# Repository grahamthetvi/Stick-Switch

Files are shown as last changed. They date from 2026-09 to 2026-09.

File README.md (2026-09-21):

# Stick-Switch

Single-axis **forward** pencil-grip stick for two-level AAC / iPad Switch Control. Soft→hard is an **upgrade** (HID `1` then `2`), never a double-select. The APH Adaptable Stick Switch (`1-08615-00`) stays the binary classroom backup on the **full** kit.

Student motion: thumb + index **push forward**. Not a 360° wobble.

## Kits

Same printed chassis for all three. Sensor methods 2 / 3 / 4a / 4b are modules that drop into that chassis; they are not separate prints.

| Kit | Cost | Power | What you get |
| --- | --- | --- | --- |
| **Wired** | Affordable | None | Method 3 D2F clicks + 3.5 mm TS cord. Binary PowerLink / switch-box. |
| **USB bank** | Affordable | USB power bank → ESP32 | Two-level BLE HID, analog modules, FET jack. No AA / boost. `PACK USB`. |
| **Full** | Full | 2× or 3× AA + boost | Same as USB bank, self-contained. APH on GPIO33. Classroom default if you want in-chassis power. |

Start **wired** to trial the click feel. Add the ESP32 on USB for two-level HID. Move to **full** when you want the pack inside the box.

Later sensor swaps (same chassis): Method 4b if travel is too small (chassis-mounted TAL220 saddle — it does **not** fit the 40×32 mm pocket). Method 2 if clicks are disliked. Method 4a for software trip points.

## What to print

Shared print list (part, material, and bed orientation). All three kits:

| Part | Material | Notes |
| --- | --- | --- |
| `base_chassis` | PETG | Floor on the bed |
| `cover_slot` | PETG | Interior face on the bed |
| `rocker_arm` | PETG | Hub face on the bed; bearings are in the towers only |
| `stick_collar` | PETG | |
| `grip_sleeve` `bellows` `tpu_foot` ×4 | TPU 95A | |
| `p_clip` | PETG | Pad on the bed; TPU 95A optional for extra grip. Print a **second** for USB-bank cable. |
| `mod3_switch_plate` | PETG | ID resistor **10k** to GND (skip the resistor on wired-only) |
| `mod3_ramp_cam` | PETG | Optional |
| `aa_2x_shim` | PETG | **Full** kit only, and only if using a 2x AA holder |

Exploded look: `openscad -D 'part="kit_preview"' cad/stick_switch.scad` (not an STL).

PETG 0.20 mm, 5 perimeters, 40% gyroid. STLs: `cad/stl/` (`bash cad/export_all.sh`).

## Wired (affordable)

Method 3 clicks + a **3.5 mm TS cord**. No ESP32, AA pack, or boost. AA well and ESP32 tray stay empty. Either click closes the cord — **binary** PowerLink / switch-box. Two-level HID needs [USB bank](#usb-bank-affordable) or [Full](#build).

Gold D2Fs. NC taped. Flying cord through the jack hole is cheapest; SJ1-3513N is optional.

```
D2F-01F-D3 COM → cord sleeve
D2F-01-D3  COM → cord sleeve
D2F-01F-D3 NO  → cord tip
D2F-01-D3  NO  → cord tip
```

`p_clip` on the +Y inner wall, 40 mm loop. Skip ESP32, AA holder, MT3608, slide, ID resistors, 2N7000, APH, module header. Diodes are only needed when GPIO is also attached — if you will drop in an ESP32 later, populate the Method 3 1N4148 diode-OR to the jack now.

## USB bank (affordable)

Drop the ESP32 into the existing tray. USB-A → Micro-USB through the rear **18 × 12 mm** cut (cover has a matching rear-edge notch). Second `p_clip` on the −X inner floor, +Y of the USB window. User-supplied bank — some banks auto-off at low load; BLE idle usually keeps them awake.

Skip AA, boost, slide, Schottky (USB 5 V on the DevKit already powers analog + the GPIO27 FET jack). Serial `PACK USB` (DUMP `"pack":0`; no low-batt blink). Analog modules use the existing FET jack netlists. Method 3 diode-OR still works with board power off.

Flash and pair as in [Build](#build) steps 8–10, but leave the AA well empty and use `PACK USB` instead of `PACK 3`. No VIN fight (no pack).

## Build

**Full** kit: Method 3 + in-chassis AA + APH `1-08615-00` on GPIO33. Do these in order. Pin map, netlists, and later sensor methods stay in the sections below. Wired and USB-bank kits skip the AA / APH steps.

Web Serial calibrator on GitHub Pages: <https://grahamthetvi.github.io/Stick-Switch/> (this README is the build guide). Enable once: **Settings → Pages → Source: GitHub Actions**.

### 1. Print

Print the [shared list](#what-to-print). **`aa_2x_shim` only for a 2x AA holder** on this full kit.

### 2. Heat-set, hinge, cover

Brass inserts into PETG with a soldering iron. Posts stay hot — burn hazard. Let them cool before handling.

- Cover: 4× short M3 inserts in the corner posts (from the top).
- Module bay: 4× M2.5 inserts in the pocket floor (34×26 mm) — M3 does not fit the 40×32 mm plate.
- Mount: 1/4-20 insert from the underside **under the stick**, not under the AA well.
- Chassis tray and Method 4b: M3 through-slots (3.3 mm). No heat-set. D2F / Hall hardware stays M2.

Hinge: press one **623ZZ** into each tower (not the rocker). **M3×20** through both. McMaster **9271K22** LH 90° torsion spring on the left-tower 4.4 mm boss. One leg in a preload hole (start at 60°); the other on the rocker. **Do not mix 9271K21 RH.** Spring legs can fly off — eye protection, hold both legs until the cover is on.

Cover screws into the M3 inserts. Cover M3 set-screw is the travel stop (12 mm grip / 14 mm slam). 8.0 mm OD × 140 mm 6061 through `stick_collar`, TPU `grip_sleeve` over the tube, TPU `bellows` into the cover groove. Four TPU feet. `p_clip` on the +Y inner wall, −X of the jack: M3 through the clip and floor, nut on the underside, **40 mm** slack loop. 0.4 mm foam on the cover stop. Loctite 222 after a classroom trial, not before.

### 3. Wire Method 3

Gold contacts only — no silver D2F on GPIO. Soft **D2F-01F-D3** → GPIO18. Hard **D2F-01-D3** → GPIO19. COM → GND. NC taped.

```
D2F-01F-D3 COM → GND
D2F-01F-D3 NO  → GPIO18 and 1N4148 anode
D2F-01-D3  COM → GND
D2F-01-D3  NO  → GPIO19 and 1N4148 anode
both 1N4148 cathodes → jack Tip
jack Sleeve → GND
ID 10k between header pin 8 and GND
```

Optional LEDs: GPIO25 soft, GPIO26 hard, GPIO16 grip (GPIO → 330 Ω → LED anode; cathode → GND). Optional piezo GPIO13.

### 4. APH backup

APH Adaptable Stick Switch **1-08615-00** on **GPIO33 + GND** the same day. Solder or a flying 3.5 mm TS pigtail (tip → GPIO33, sleeve → GND). The chassis **SJ1-3513N is PowerLink OUTPUT**, not an APH input — do not plug the APH into it.

### 5. Install AA pack

Well **60 × 50 × 18 mm** on −Y. Prefer 3x AA for the full kit. AA holder options (pack, Keystone part, Digi-Key SKU, and well fit):

| Pack | Holder | Digi-Key | Fit |
| --- | --- | --- | --- |
| 3x AA | Keystone **2465** (6″ leads) or **2464** (PC pins) | `36-2465-ND` / `36-2464-ND` | ~58 × 48 × 17 mm |
| 2x AA | Keystone **2463** (6″ leads) or **2462** (PC pins) | `36-2463-ND` / `36-2462-ND` | ~58 × 32 × 17 mm; print `aa_2x_shim` into +Y slack |

Snap-on 9V-style Keystone **2475** (3x) / **2474** (2x) also fit; add a 9V snap pigtail. Amazon clones are fine if they measure those envelopes. (Older notes said 2468 / 2466-class — those SKUs are AAA / not this well.)

```
holder + → SS-12F15 → MT3608 IN
MT3608 5.0 V → 1N5819/SS14 Schottky → ESP32 VIN
holder − → GND
100k / 100k from pack + → GPIO34 → GND
```

Alkaline AA, polarity as marked on the holder. **No in-chassis charging.** Slide **OFF** while programming (USB 5 V fights VIN if the switch is ON). Serial `PACK 2` or `PACK 3`. No AA: [USB bank](#usb-bank-affordable) and `PACK USB`.

### 6. Connect PowerLink

Same Sky **SJ1-3513N**: tip = NO, sleeve = GND, ring unused. 3.5 mm **TS** cable from this jack into the AbleNet PowerLink **SWITCH** jack. Independent of BLE and of `PROFILE`. Method 3 diode-OR closes the jack with the ESP32 **off**. Analog FET (GPIO27 / 2N7000) needs board power.

### 7. Grip LED (optional)

Isolate the 6061 tube in the PETG `stick_collar`. Run a wire from the tube (collar slot) to GPIO14 (touch T6). LED on GPIO16 only — never HID, never jack. Serial `GRIP CAL` at rest; `GRIP THRESH <n>` if needed.

### 8. Flash

Install [PlatformIO Core](https://docs.platformio.org/en/latest/core/installation/index.html) (or the VS Code PlatformIO IDE). Slide switch OFF.

```
cd firmware/stick_switch
pio run -e esp32dev --target upload
pio device monitor -b 115200
```

If upload fails: hold **BOOT**, tap EN, release BOOT, retry. Type `HELP` then `DUMP`.

### 9. First boot

Slide ON. Serial:

```
PACK 3
PROFILE IPADOS
```

Use `PACK 2` if the holder is 2x AA. Pair BLE keyboard `Stick-Switch-XXXX` (last two MAC bytes). iPad **Settings → Accessibility → Switch Control → Switches → External**: `1` = Move to Next Item, `2` = Select Item. Chrome/Edge calibrator: <https://grahamthetvi.github.io/Stick-Switch/> (`tools/calibrate.html`, Web Serial, 115200). Method 3 clicks need **no** analog CAL.

### 10. Full-kit bench

Same checks as [Bench](#bench-all-methods) below: luggage scale, `PLOT 1`, Notes app `1` then `2`, Method 3 jack continuity with power off.

## HID / iPad

Pair the ESP32 BLE keyboard named `Stick-Switch-XXXX` (last two MAC bytes; manufacturer **Graham Labs**). Then **Settings → Accessibility → Switch Control → Switches → External**:

- `1` = Move to Next Item
- `2` = Select Item

Firmware never holds both keys. Crossing hard **releases the soft key and presses the hard key**. Easing off hard without a full release stays on hard. Full release clears keys. Profiles change which HID codes those levels send; they do **not** change the jack.

HID key map by `PROFILE` (soft, hard, and binary/APH):

| `PROFILE` | Soft | Hard | Binary / APH |
| --- | --- | --- | --- |
| `IPADOS` (default) | `1` | `2` | Space |
| `ANDROID` | Tab | Return | Return |
| `FUNCTION` | F1 | F2 | F3 |
| `MEDIA` | vol down | vol up | play/pause |
| `CUSTOM` | NVS `KEYS` / `BINARY_KEY` | | |

Serial: `PROFILE IPADOS`, `MODE BINARY`, `BINARY_KEY SPACE`. `KEYS` / `BINARY_KEY` switch to `CUSTOM` and persist.

## Firmware

ESP32 DevKit V1 / WROOM, PlatformIO env `esp32dev` (`firmware/stick_switch`). Uses NimBLE + ESP32 BLE Keyboard. **ADC1 only** (GPIO32 sensor, GPIO34 battery, GPIO35 module ID). Do not use ADC2 — BLE owns the radio.

```
cd firmware/stick_switch
pio run -e esp32dev --target upload
pio device monitor -b 115200
```

If upload fails, hold **BOOT**, tap EN, release BOOT. Full-kit procedure: [Build](#build). USB-bank: [USB bank](#usb-bank-affordable). Wired has no firmware.

Native policy tests (no hardware):

```
make -C firmware/native_test test
```

USB serial 115200. `HELP` lists commands. Chrome/Edge calibrator: <https://grahamthetvi.github.io/Stick-Switch/> (same file as `tools/calibrate.html`; Web Serial needs HTTPS or localhost). Wizard is Rest/TARE → hold soft/CAL SOFT → hold hard/CAL HARD. `MODE`, `PROFILE`, `PACK` (`2` / `3` / `USB`), `TARE`, `CAL STOP`, `KEYS`, `BINARY_KEY`, `INVERT`, `LUT`, `SCALE`, `GRIP THRESH`, and `GRIP CAL` **auto-save to NVS**. Classroom power-cycle keeps cal. `SAVE` is still an explicit dump confirmation.

BOOT button (GPIO0, after setup): 1 tap = simulate soft, 2 taps = simulate hard, hold = TARE (or CAL start/stop if already collecting / analog held). Optional piezo on GPIO13: startup, paired, click, low battery (silent if unpopulated).

ESP32 pin map (GPIO and function):

| GPIO | Function |
| --- | --- |
| 0 | BOOT diagnostics (INPUT_PULLUP after setup) |
| 18 | SW_SOFT (INPUT_PULLUP) |
| 19 | SW_HARD (INPUT_PULLUP) |
| 33 | APH backup (INPUT_PULLUP) |
| 32 | ADC FSR / Hall (ADC1_CH4) |
| 34 | Pack millivolts (ADC1_CH6), 100k/100k from pack + |
| 35 | Module ID (ADC1_CH7), header pin 8 |
| 21 / 22 | I2C SDA / SCL (NAU7802) |
| 4 | TARE |
| 23 | CAL (reserved; serial is primary) |
| 25 / 26 | LED soft / hard |
| 16 | LED grip (indicator only — never HID, never jack) |
| 27 | JACK_OUT → 2N7000 gate (PowerLink) |
| 14 | Capacitive grip (T6) on isolated 6061 tube |
| 13 | Optional piezo earcon |

NVS modes: `MICRO` `FSR` `HALL` `LOAD` `BINARY`. On boot a valid module ID sets the matching mode; serial `MODE` still overrides for this session (and auto-saves). Empty header keeps the NVS mode. `DUMP` JSON includes `mode`, `profile`, `ble_name`, `level`, `batt_mv`, `batt_pct`, `pack`, `grip`, `module_id`, `module_ohms`, and cal fields. `pack` is `2` / `3` for AA or `0` for `PACK USB`. Idle low-batt LED blink follows the selected AA pack curve (≤15%); USB pack never reports low. Grip hold lights GPIO16 only.

Module ID table (plate, resistor to GND, and `module_id`; 47k pull-up to 3V3 on the chassis):

| Plate | Resistor | `module_id` |
| --- | --- | --- |
| Method 3 | 10k | `MICRO` |
| Method 2 | 22k | `FSR` |
| Method 4a | 47k | `HALL` |
| Method 4b | 100k | `LOAD` |
| none | open | `EMPTY` |

## AA power well and packs

Chassis is **110 × 108 × 32 mm**. One well on the −Y side, **60 × 50 × 18 mm**, takes a 3x AA holder (Keystone **2465** / **2464**, Digi-Key `36-2465-ND` / `36-2464-ND`, ~58 × 48 × 17 mm). A 2x AA holder (Keystone **2463** / **2462**, `36-2463-ND` / `36-2462-ND`, ~58 × 32 × 17 mm) locates in the same well against −Y; print `aa_2x_shim` into the leftover +Y slack. MT3608 sits +X of the holder. No TP4056 — **do not charge AA cells in the chassis**. The 1/4-20 insert stays under the stick, not under the pack. ESP32 stays in the aisle between the towers.

```
AA holder (2x or 3x series) → SS-12F15 slide → MT3608 IN
MT3608 5.0 V → 1N5819/SS14 Schottky → ESP32 VIN
100k / 100k from pack + → GPIO34 → GND
Program: ESP32 USB with the slide switch OFF
```

Serial `PACK 2` / `PACK 3` / `PACK USB` (NVS). Unset pack auto-picks from millivolts on boot (≥3.3 V → 3cell). Curves: 2x empty ~2.0 V full ~3.2 V; 3x empty ~3.0 V full ~4.8 V. BLE HID battery percent and idle low-batt LED use that curve. USB-bank builds skip the AA well: `PACK USB` reports 100% and does not blink low-batt (GPIO34 is floating with no divider).

If USB is live and the switch is ON, 5 V fights at VIN — leave the slide **OFF** while programming. The Schottky stops USB from backfeeding the boost. USB-only (no pack) has no VIN fight.

## PowerLink jack

Same Sky **SJ1-3513N** 3.5 mm TRS, tip = NO, sleeve = GND, ring unused (APH TS plug mates). This is the **PowerLink / wired switch-box output**. It is independent of BLE connection and of `PROFILE`. Method 3 **diode-OR still closes the jack with the ESP32 off**. Analog modules (FSR / Hall / 4b) drive the jack with a 2N7000 from GPIO27 — that path **dies with the board**.

## Grip LED (tube sensor)

Wire the isolated 6061 tube (PETG `stick_collar`) to GPIO14 (touch T6). `touchRead` below the NVS threshold lights GPIO16 only — never HID, never jack. Serial `GRIP THRESH <n>`, `GRIP CAL` (at rest). Fallback: two foil bands on the TPU sleeve, 3.3 V through 1 MΩ, ADC; do not run meaningful current through the student.

## Shared chassis

OpenSCAD: `cad/stick_switch.scad`. STLs: `cad/stl/` (regenerated from this scad; `part="kit_preview"` is exploded shared print only). Export: `bash cad/export_all.sh`. `base_chassis` may warn “not a valid 2-manifold” in OpenSCAD; it is one solid and slices.

Print PETG, 0.20 mm, 5 perimeters, 40% gyroid, no living hinge as the return spring. Shared chassis materials for all three kits (not only the [print list](#what-to-print)):

| Part | Material |
| --- | --- |
| `base_chassis` `cover_slot` `rocker_arm` `stick_collar` `p_clip` | PETG |
| `grip_sleeve` `bellows` `tpu_foot` (×4) `magnet_plug` | TPU 95A |
| Module plates | PETG (TPU puck only on Method 2) |

Tolerances: M3 holes and tray slots 3.3 mm, 623ZZ seats 10.1 mm (`$fn` 72), stick slot 8.4 mm (Y) × 12 mm (X), module pocket 40×32 mm, M2.5 pattern 34×26 mm. D2F / Hall stay M2. Stick: **8.0 mm OD × 140 mm 6061**, grip center **110 mm** from hinge. Cam at **25 mm**. Cover M3 set-screw is the travel stop (12 mm grip / 14 mm slam; **0.4 mm cam** for Method 4b).

Return: McMaster **9271K22** left-hand 90° piano-wire torsion spring (0.281″ OD, 0.172″ shaft, 0.030″ wire, 3.25 coils, 1″ legs, 0.67 in·lbf max at 90°). Do not mix **9271K21** RH. Printed 4.4 mm boss on the left tower; preload holes 0/30/60/90° at 7.5 mm radius. Start at 60° (≈0.5 N at the grip); 90° if the stick feels light. Target **0.5–0.7 N** at grip (luggage scale). Hinge: M3×20 + two **623ZZ in the towers**. Side-load is killed by the cover slot. Mount: 1/4-20 insert, 4× M3 tray slots, Dual Lock SJ3550, TPU feet. Cord: printed `p_clip` + 40 mm loop. USB power-bank: rear-wall **18 × 12 mm** cut + cover notch; second `p_clip` on the −X inner floor. Pinch: TPU bellows, edges R≥2 mm.

8-pin module header (rear, pin 1 = 3V3): `3V3, GND, SOFT, HARD, ADC, SDA, SCL, ID`. ID → GPIO35.

PowerLink jack: Same Sky **SJ1-3513N**. Tip = NO, Sleeve = GND, Ring unused (APH TS plug mates).

## Method 3 — staged microswitches (first trial)

- Soft: Omron **D2F-01F-D3** (0.74 N, gold, solder lug)
- Hard: Omron **D2F-01-D3** (1.47 N, gold)
- `mod3_switch_plate` + optional `mod3_ramp_cam`
- Hard switch **1.6 mm** further from the cam. Target grip travel **4–6 mm / 10–12 mm / 14 mm stop**. 0.4 mm foam on the stop.

Wiring (COM→GND, NO→GPIO, NC taped):

```
D2F-01F-D3 COM → GND
D2F-01F-D3 NO  → GPIO18 and 1N4148 anode
D2F-01-D3  COM → GND
D2F-01-D3  NO  → GPIO19 and 1N4148 anode
both 1N4148 cathodes → jack Tip
jack Sleeve → GND
ID 10k between header pin 8 and GND
```

Firmware: `MODE MICRO`. 1 kHz poll, 15 ms debounce. HARD if GPIO19 low (even if GPIO18 failed). No downgrade until both high 15 ms. Jack still works with ESP32 **off** (diode-OR). No-ESP32 parallel-to-cord wiring: [Wired](#wired-affordable).

Do not use silver D2F parts on GPIO.

## Method 2 — FSR

Adafruit **#166** (Alpha MF01A-N-221-A01) or Interlink **34-00012**. `mod2_anvil` + TPU `mod2_puck` Ø8×3 + `mod2_retainer` (1.4 mm, printable). Do not solder the FSR tail.

```
FSR A → 3V3
FSR B → GPIO32 and 47k to GND
100 nF GPIO32 → GND
GPIO27 → 10k to GND and 2N7000 gate
2N7000 drain → jack Tip; source → GND
ID 22k between header pin 8 and GND
```

`MODE FSR`. 200 Hz, boxcar/8, 8% hysteresis. Until cal: soft = tare+250, hard = tare+1200. Then `TARE`, five hard holds, `CAL START HARD` / `CAL STOP` (stores 35% / 70% of span). Jack FET is dead when the ESP32 is off.

## Method 4a — Hall travel

Honeywell **SS49E** + encapsulated **6×3 mm N35** (not N52). Rest gap 5 mm, stop gap 2 mm. Brass/nylon M2. `mod4a_hall_tray` + `gap_gauge_2`…`6` + `magnet_plug`.

Honeywell TO-92 (verify bag): pin1 Vcc, pin2 GND, pin3 OUT.

```
Vcc → 3V3   GND → GND   OUT → GPIO32
100 nF Vcc–GND   10 nF OUT–GND
jack FET as Method 2
ID 47k between header pin 8 and GND
```

South toward branded face must **raise** ADC; else `INVERT AN 1` or flip magnet. `MODE HALL`. 5-point LUT:

```
LUT 1800,0,2000,3,2300,6,2700,9,3100,12
```

Sweep grip 0–12 mm; span must be ≥800 counts. Soft 5 mm / hard 11 mm / hyst 0.8 mm. Tares at BLE connect via rest ADC (`TARE`). If the student mouths objects, skip this module.

## Method 4b — load cell (later; near-zero travel)

SparkFun **SEN-13329 TAL220 10 kg** (or YZC-133 5 kg) is **55 × 12.7 mm** and does not fit the 40×32 mm module pocket. `mod4b_cell_saddle` is a **72 × 24 mm** chassis-mounted beam that bolts to the M3 slots under the cam — not a 40 mm plate. The TAL220 bar's own holes stay the vendor size (usually M5). Later experiment, not first-print. Adafruit **4538** NAU7802, gain 128, LDO 3.0 V, 80 SPS. `mod4b_ball_anvil`, `feeler_0_4` (0.4 mm **gauge**, not a structural part). Set cover stop to **0.4 mm** cam motion.

```
Red → E+   Black → E−   Green → A+   White → A−
NAU VIN→3V3  GND→GND  SDA→GPIO21  SCL→GPIO22
(no extra I2C pull-ups on STEMMA)
ID 100k between header pin 8 and GND
```

`MODE LOAD`. Soft 120 gf / hard 300 gf / hyst 25 gf until student cal. Quiet slow-tare 1%/3 s only when abs(g) < 15. I2C fail → APH GPIO33 still works. Clone color-code: `INVERT LD 1`. Scale with 500 g on the **grip**: `SCALE <gf_per_count>`. Jack FET is dead when the ESP32 is off.

## Bench (all methods)

1. Luggage-scale **10 presses** at the grip; rewrite thresholds from that, not from 1.2 / 3.0 N defaults.
2. Serial `PLOT 1`: 20 slow, 20 fast, 10 slams. Dual-fire count must be 0.
3. iPad Notes: one stroke types `1` then `2`, never overlapping `12`.
4. Switch Control mapping as above.

Method 3 extra: continuity on each NO; jack closes on either click with power off.

## Student trial (10 min, eyes-free after demo)

Watch: two distinct levels, accidental hard, fatigue, resting on the stick (false soft), inability to unload (spring too strong). Abort the last. Method 4b: “push harder, don’t push farther.”

## Safety

Bellows over the hinge. Encapsulated magnet only. No loose neodymium. Clip the cord with printed `p_clip` (40 mm loop). Overload posts on 4b. Loctite 222 after classroom trial. Alkaline AA only; polarity as marked; no in-chassis charging. Slide switch off in a bag. Heat-set posts burn. Hold **9271K22** legs until the cover is on (do not mix **9271K21** RH).

## BOM

Machine-readable list: [`hardware/bom.csv`](hardware/bom.csv). `used_on` includes `wired` and `usb_bank` (the two affordable kits) plus `full` for in-chassis AA power. Shared mechanics are tagged `wired` because every kit prints them.

## GitHub Pages

<https://grahamthetvi.github.io/Stick-Switch/> is the Web Serial calibrator (canonical HTML: `tools/calibrate.html`). This README is the build guide. Workflow `.github/workflows/pages.yml` copies that file to the Pages artifact as `index.html` (static deploy, not Jekyll). Enable once: repo **Settings → Pages → Build and deployment → Source: GitHub Actions**. Use Chrome or Edge; USB serial **115200**. GitHub Pages is HTTPS (required for Web Serial). Safari and Firefox cannot use Web Serial. The same page includes a USB **data**-cable check (plug a known-working USB device through the cable under test); it does not test 3.5 mm PowerLink / TS cords.

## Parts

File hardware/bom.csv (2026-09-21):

qty | mfr_pn | source | used_on | role
1 | ESP32 DevKit V1 WROOM | Adafruit/Amazon | full,usb_bank | BLE HID MCU; full kit and USB-bank (skip AA on usb_bank)
1 | USB-A to Micro-USB cable | Amazon | usb_bank | Power bank to DevKit V1 USB; user supplies the bank (some banks auto-off at low load)
1 | Keystone 2465 (Digi-Key 36-2465-ND) or 2464 (36-2464-ND) | Digi-Key | full | 3x AA holder ~58x48x17 mm in the 60x50x18 mm well; 2465=6in leads 2464=PC pins; snap-on 2475 also fits
1 | Keystone 2463 (Digi-Key 36-2463-ND) or 2462 (36-2462-ND) | Digi-Key | full | 2x AA holder ~58x32x17 mm; print aa_2x_shim on the +Y side (omit if using 3x); snap-on 2474 also fits
1 | MT3608 boost module (set 5.0 V) | Amazon | full | Pack to 5 V for ESP32 VIN
1 | SS-12F15 or similar SPDT slide | Digi-Key/Amazon | full | Pack switch between holder + and boost VIN
2 | 100k 1% TH | Digi-Key | full | GPIO34 battery divider from pack + (before boost)
1 | 1N5819 or SS14 Schottky | Digi-Key | full | Boost 5 V to ESP32 VIN (blocks USB backfeed into boost)
1 | passive piezo 12 mm (optional) | Digi-Key | chassis | Earcons on GPIO13; omit for silent
3 | 3mm LED + 330R | Digi-Key | chassis | GPIO25 soft / GPIO26 hard / GPIO16 grip (GPIO to R to LED anode; cathode to GND); omit if unused
1 | 3.5 mm TS (2-conductor) patch cable 1-2 m | Amazon/AbleNet | powerlink,wired | Chassis SJ1-3513N or flying cord to AbleNet PowerLink SWITCH jack
2 | printed p_clip (cad/stl/p_clip.stl) | print | chassis,wired,usb_bank | PETG P-clip; one on +Y inner wall −X of jack (40 mm loop); second on −X inner floor for USB-bank cable
2 | M3x8 or M3x10 + nut | Amazon | chassis,wired,usb_bank | p_clip to chassis floor (nut underside); second fastener for USB p_clip
1 | 0.4 mm foam pad | Amazon | method3,wired | Cover travel-stop pad
1 | 24 AWG stranded hookup wire | Digi-Key | chassis,wired | GPIO power jack APH pigtail; wired kit D2F to cord
1 | Loctite 222 purple threadlocker | McMaster/Henkel | chassis,wired | After classroom trial (not before)
1 | wire to 6061 stick (PETG collar isolate) | Digi-Key | chassis | ESP32 touch T6 GPIO14; grip LED GPIO16 only
1 | 47k 1% TH | Digi-Key | chassis | Module ID pull-up GPIO35 to 3V3
1 | 10k 1% TH | Digi-Key | method3 | Module ID resistor to GND (MICRO)
1 | 22k 1% TH | Digi-Key | method2 | Module ID resistor to GND (FSR)
1 | 47k 1% TH | Digi-Key | method4a | Module ID resistor to GND (HALL)
1 | 100k 1% TH | Digi-Key | method4b | Module ID resistor to GND (LOAD)
2 | 623ZZ | Amazon/AliExpress | chassis,wired | Hinge bearings 3x10x4 mm (towers only)
1 | M3x20 steel shoulder or socket cap | McMaster/Amazon | chassis,wired | Hinge pin
1 | 9271K22 | McMaster | chassis,wired | LH 90° piano-wire torsion spring (0.281" OD 0.172" shaft 0.030" wire 3.25 coils 1" legs); do not mix 9271K21 RH
1 | 8.0 mm OD x 1.0 mm wall 6061 tube 140 mm | McMaster | chassis,wired | Pencil-grip stick (touch electrode; PETG collar isolates the grip sleeve)
1 | Same Sky SJ1-3513N | Digi-Key | chassis,wired | PowerLink 3.5 mm TRS jack (tip=NO sleeve=GND); omit on wired-only if using a flying TS cord
1 | 1/4-20 brass heat-set insert | Amazon | chassis,wired | RAM/Manfrotto mount (not under the pack)
4 | M3x10 + nuts (optional) | Amazon | chassis,wired | Tray through-slots; Dual Lock / 1/4-20 work without them
8 | M3 heat-set inserts short | Amazon | chassis,wired | Cover + stick pinch
4 | M2.5x8 + inserts | Amazon | module bay,wired | Module screws 34x26 mm
1 | 2N7000 N-FET | Digi-Key | analog modules,usb_bank | Jack drive GPIO27
1 | 10k 1% TH | Digi-Key | analog modules,usb_bank | 2N7000 gate pulldown
1 | 8-pin 2.54 header pair | Digi-Key | module,usb_bank | 3V3 GND SOFT HARD ADC SDA SCL ID
1 | Omron D2F-01F-D3 | Digi-Key/Mouser | method3,wired | Soft click 0.74 N gold microload
1 | Omron D2F-01-D3 | Digi-Key/Mouser | method3,wired | Hard click 1.47 N gold microload
2 | extra D2F-01F-D3 / D2F-01-D3 | Digi-Key | method3,wired | Spares
4 | M2x8 pan + hex nuts | Amazon | method3,wired | Switch slots
2 | 1N4148 (or BAT54) | Digi-Key | method3,wired | Jack diode-OR; omit on wired-only unless adding ESP32 later
1 | Adafruit 166 Alpha MF01A-N-221-A01 | Adafruit | method2 | 14.7 mm FSR 0.3-10 N
2 | spare FSR 166 or Interlink 34-00012 | Adafruit/Digi-Key | method2 | Tail-tear spares
1 | 47k 1% resistor | Digi-Key | method2 | FSR pulldown
1 | 100 nF ceramic | Digi-Key | analog modules | ADC RC (method 2 FSR / 4a Hall GPIO32)
1 | Honeywell SS49E | Digi-Key/Mouser | method4a | Linear Hall TO-92
2 | 6x3 mm N35 disc magnet | K&J/Amazon | method4a | One installed one spare
1 | 100 nF Vcc | Digi-Key | method4a | Hall decoupling
1 | 10 nF | Digi-Key | method4a | Hall output filter
2 | M2x8 nylon/brass | Amazon | method4a | Non-ferrous gap slot
1 | SparkFun SEN-13329 TAL220 10 kg | SparkFun | method4b | Load cell (YZC-133 5 kg substitute); chassis-mounted saddle not 40 mm plate
1 | Adafruit 4538 NAU7802 | Adafruit | method4b | 24-bit I2C ADC
1 | STEMMA QT / Qwiic cable | Adafruit | method4b | I2C
1 | Ø5 mm steel ball | McMaster | method4b | Anvil
2 | M3x10 locknuts | Amazon | method4b | Saddle to chassis M3 slots under cam
1 | APH 1-08615-00 | APH | backup | Existing binary wobble stick
1 | PETG filament | Amazon | print,wired | Structural
1 | TPU 95A filament | Amazon | print,wired | Grip bellows feet puck plug
1 | 3M Dual Lock SJ3550 | 3M | mount,wired | Tray pads

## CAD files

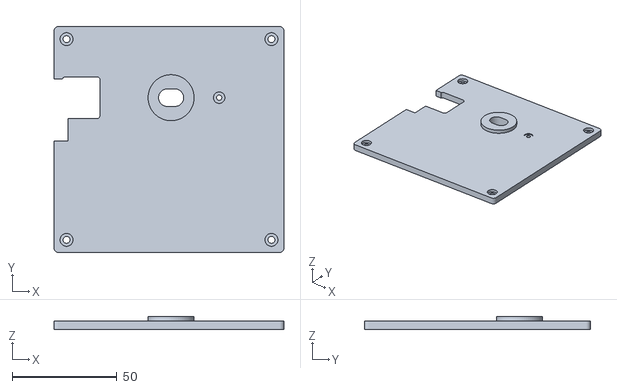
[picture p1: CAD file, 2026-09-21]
cad/stl/cover_slot.stl
110.0 x 108.0 x 6.20

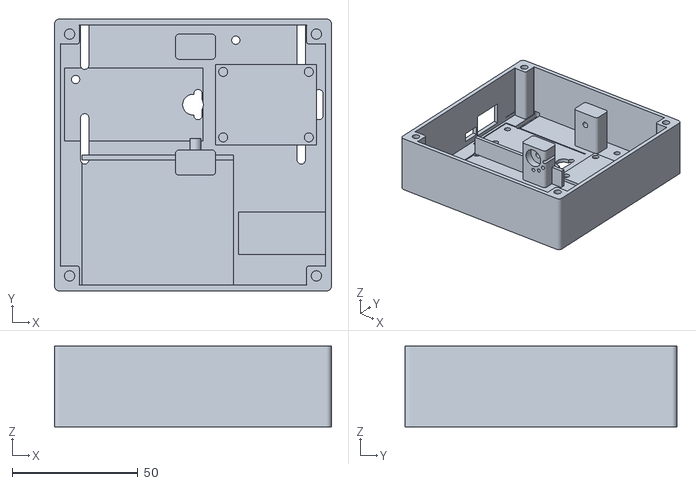
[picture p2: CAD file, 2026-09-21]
cad/stl/base_chassis.stl
110.0 x 108.0 x 32.0

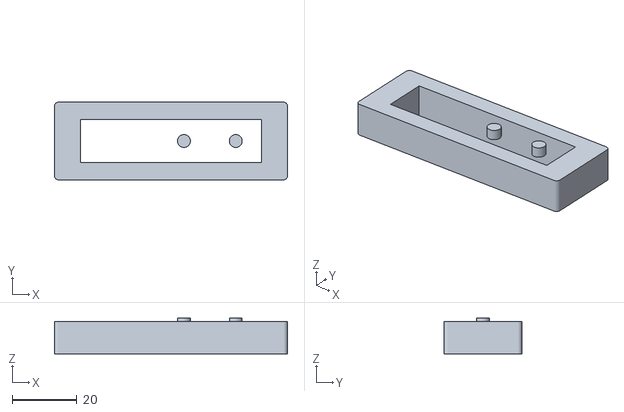
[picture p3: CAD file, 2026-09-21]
cad/stl/mod4b_cell_saddle.stl
72.0 x 24.0 x 11.0

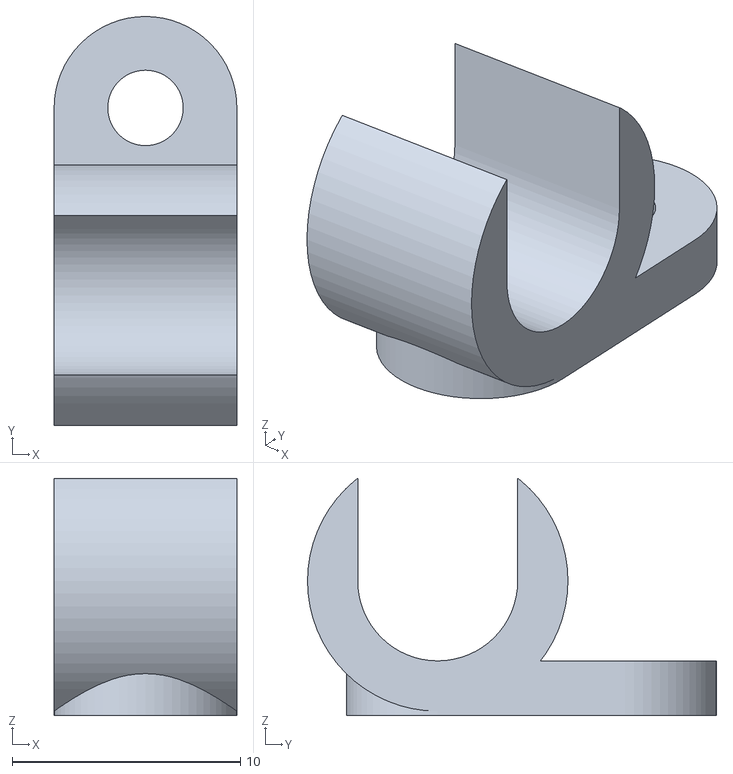
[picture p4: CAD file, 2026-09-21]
cad/stl/p_clip.stl
8.00 x 17.9 x 10.4

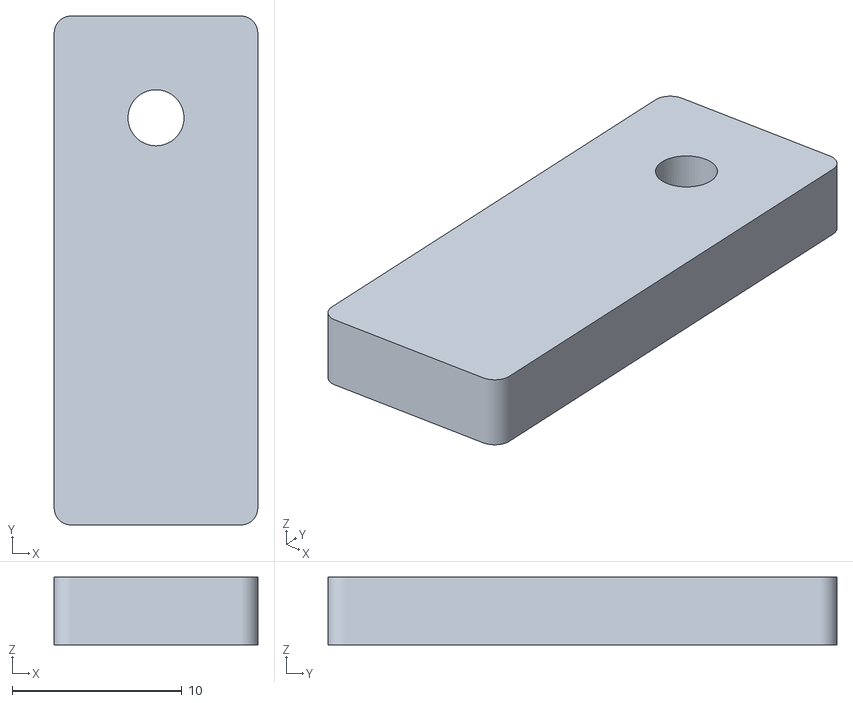
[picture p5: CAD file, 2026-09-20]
cad/stl/gap_gauge_4.stl
12.0 x 30.0 x 4.00

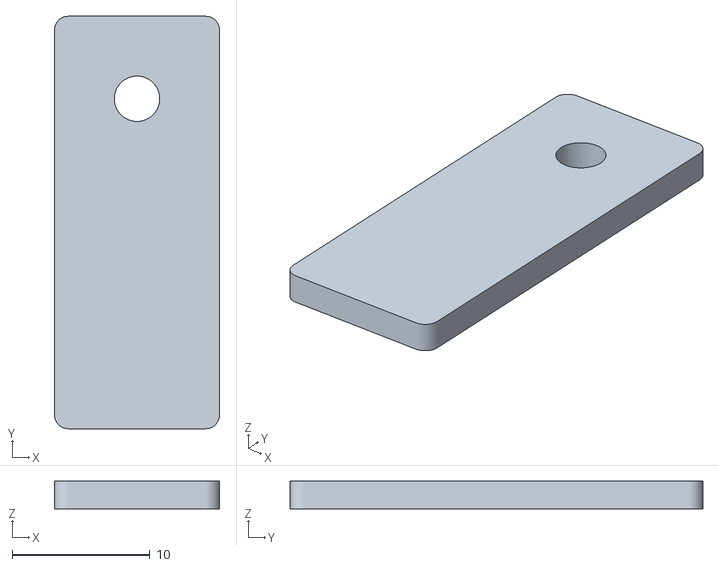
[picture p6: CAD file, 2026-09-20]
cad/stl/gap_gauge_2.stl
12.0 x 30.0 x 2.00

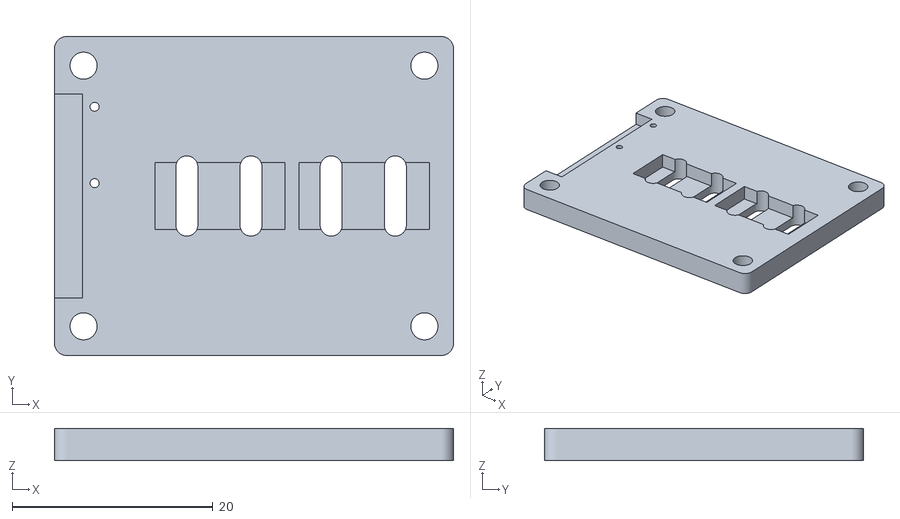
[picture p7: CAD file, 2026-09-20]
cad/stl/mod3_switch_plate.stl
39.8 x 31.8 x 3.20

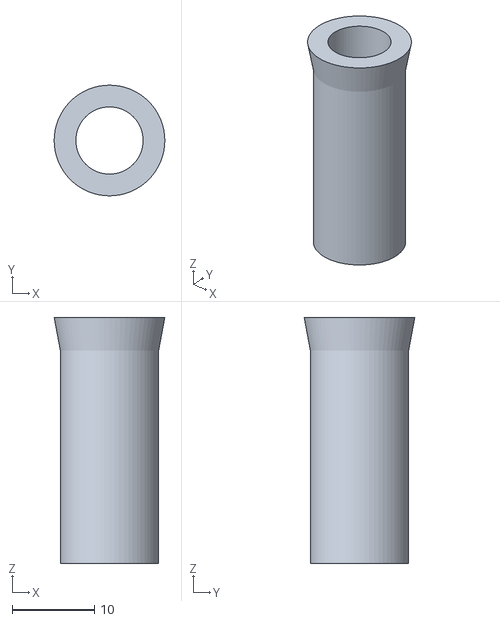
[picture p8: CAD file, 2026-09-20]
cad/stl/grip_sleeve.stl
13.5 x 13.5 x 30.0

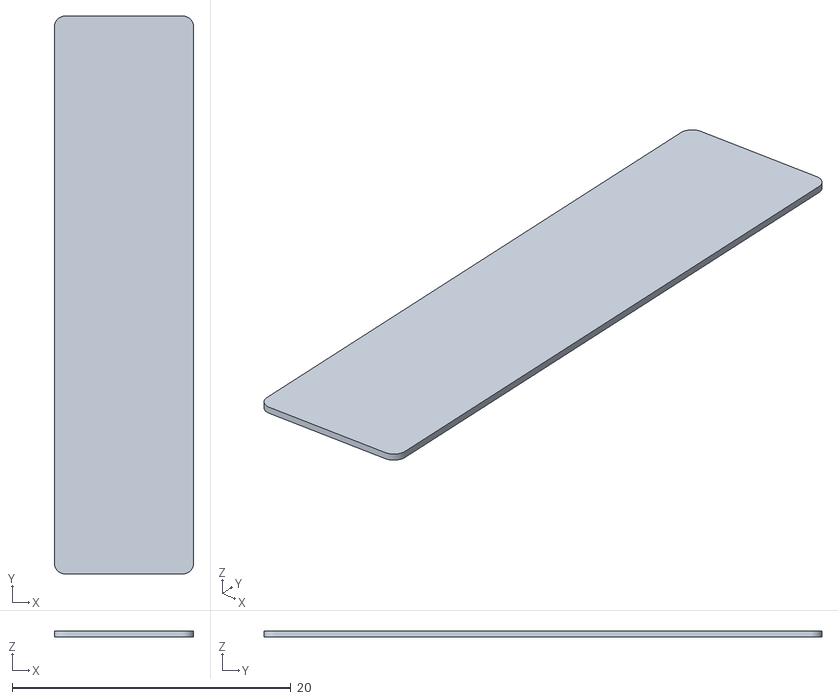
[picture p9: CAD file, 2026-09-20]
cad/stl/feeler_0_4.stl
10.0 x 40.0 x 0.4

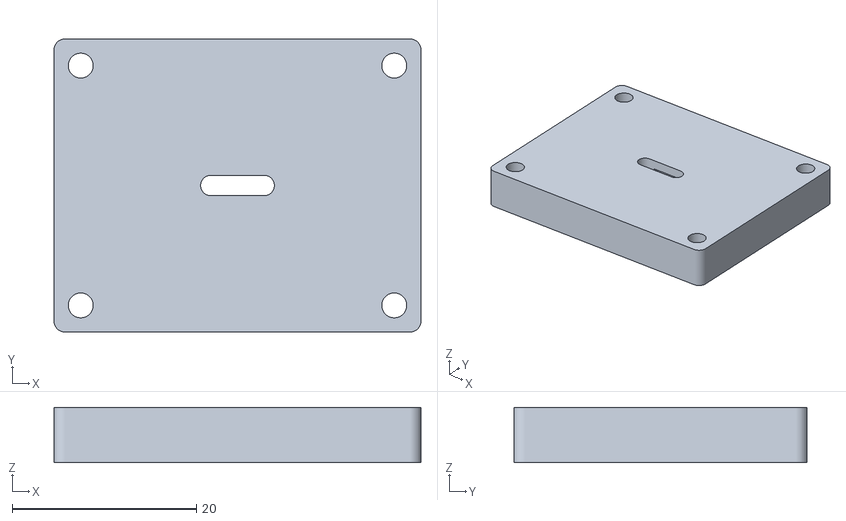
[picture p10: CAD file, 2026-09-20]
cad/stl/mod4a_hall_tray.stl
39.8 x 31.8 x 6.00

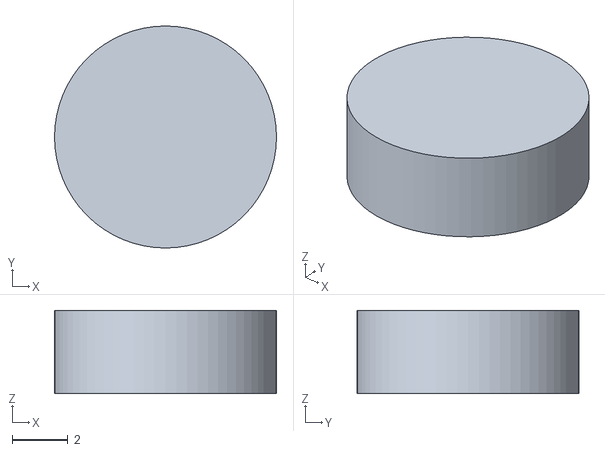
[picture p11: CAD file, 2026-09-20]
cad/stl/mod2_puck.stl
8.00 x 8.00 x 3.00

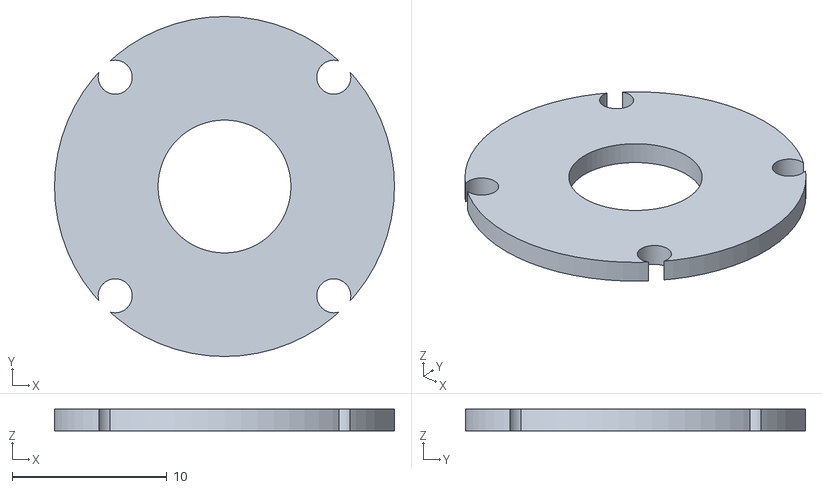
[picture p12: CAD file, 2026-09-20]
cad/stl/mod2_retainer.stl
22.0 x 22.0 x 1.40

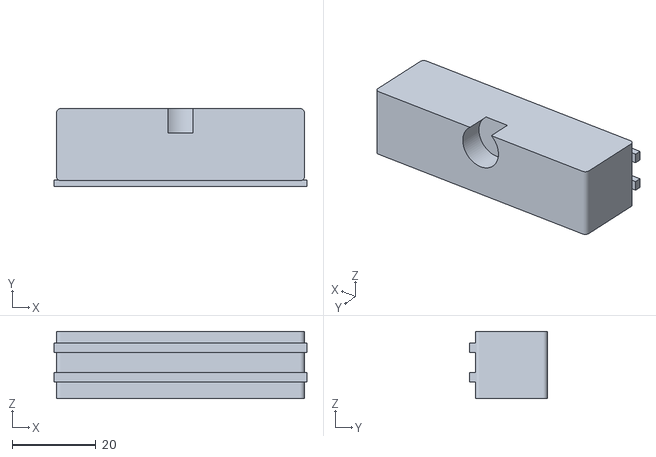
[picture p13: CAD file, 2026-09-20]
cad/stl/aa_2x_shim.stl
60.4 x 18.6 x 16.0

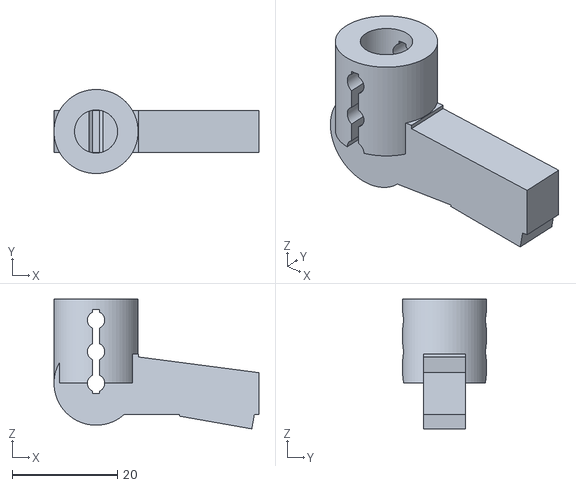
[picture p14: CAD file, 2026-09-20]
cad/stl/rocker_arm.stl
39.0 x 16.0 x 24.7

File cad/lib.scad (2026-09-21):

// Shared helpers for Stick-Switch printable parts.
// Units: millimetres. External edges aim for R >= 2 mm.

$fn = 64;

module rounded_box(size, r = 2, center = false) {
  x = size[0];
  y = size[1];
  z = size[2];
  rr = min(r, x / 2 - 0.05, y / 2 - 0.05);
  o = center ? [-x / 2, -y / 2, -z / 2] : [0, 0, 0];
  translate(o)
    hull() {
      for (px = [rr, x - rr])
        for (py = [rr, y - rr])
          translate([px, py, 0])
            cylinder(h = z, r = rr);
    }
}

module slot_xy(length, width, height) {
  hull() {
    translate([-length / 2 + width / 2, 0, 0])
      cylinder(h = height, d = width);
    translate([length / 2 - width / 2, 0, 0])
      cylinder(h = height, d = width);
  }
}

module countersink_m3(h = 3.5) {
  cylinder(h = h + 0.2, d = 6.2);
}

module m3_clearance(h = 20) {
  cylinder(h = h, d = 3.3);
}

module m3_insert(h = 6.0) {
  // 0.1 mm over typical short M3 heat-set insert OD ~4.0 mm
  cylinder(h = h, d = 4.1);
}

module m25_insert(h = 5.0) {
  cylinder(h = h, d = 3.6);
}

module m2_clearance(h = 12) {
  cylinder(h = h, d = 2.2);
}

module m3_slot(length = 20, h = 12) {
  slot_xy(length, 3.3, h);
}

module bearing_623zz_seat(depth = 4.2) {
  cylinder(h = depth, d = 10.1, $fn = 72);
}

module through(h, d) {
  translate([0, 0, -0.2])
    cylinder(h = h + 0.4, d = d);
}

// Two 0.9 mm holes, 7.62 mm pitch, for the module ID resistor (TH 1/4 W).
// Solder between header pin 8 (ID) and pin 2 (GND).
module module_id_resistor_cut() {
  translate([4.0, 0, -0.2]) {
    cylinder(h = 6, d = 0.9);
    translate([0, -7.62, 0])
      cylinder(h = 6, d = 0.9);
  }
}

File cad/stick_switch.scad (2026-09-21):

// Stick-Switch shared single-axis chassis and sensor modules.
// Generate one STL:  openscad -D 'part="base_chassis"' -o cad/stl/base_chassis.stl cad/stick_switch.scad
// Shared print for all three kits (wired / USB bank / full): part="kit_preview".
//
// Coordinate system (base origin = rear-left-bottom of chassis):
//   +X forward (student push / toward sensor bay)
//   +Y left-to-right (battery on −Y, 3.5 mm jack on +Y)
//   +Z up (stick)
// Hinge axis is +Y through [hinge_x, hinge_y, hinge_z].
//
// Shared print (PETG unless noted):
//   base_chassis, cover_slot, rocker_arm, stick_collar,
//   grip_sleeve (TPU), bellows (TPU), tpu_foot x4, p_clip,
//   mod3_switch_plate, optional mod3_ramp_cam.
// USB bank: second p_clip. Full kit: aa_2x_shim only for 2x AA.
// Method 4b is a later chassis-mounted TAL220 saddle — not a 40 mm plate.

include <lib.scad>

part = "base_chassis"; // see render_part() at bottom

// Packing: 3x AA well on −Y (2x AA uses the same well + printed shim),
// MT3608 +X of the holder, ESP32 in the aisle BETWEEN the towers,
// module bay +X of ESP32. No in-chassis charger.
// tower_off=23 so the inner span (36 mm) clears the 29 mm DevKit.
base_x = 110;
base_y = 108;
base_z = 32;
wall = 2.4;
r_ext = 2.0;

hinge_x = 56;
hinge_y = 74;
hinge_z = 18; // keep cam height on Method 3 D2F plungers
cam_r = 25;
grip_r = 110;
stick_od = 8.0;
stick_slot_y = 8.4;
stick_slot_x = 12.0;
tower_off = 23;
tower_w = 10;
tower_d = 16;

module_pocket = [40, 32, 18];
module_clear = 0.2;
module_holes = [34, 26];
module_origin = [hinge_x + 8, hinge_y - module_pocket[1] / 2, wall];

cover_z = 4.0;
insert_1_4_20_d = 8.2;
insert_1_4_20_h = 10.0;

esp32 = [55, 29, 13];
esp32_origin = [wall + 1.5, hinge_y - esp32[1] / 2, wall];

// 3x AA holder (Keystone 2465/2464, ~58 x 48 x 17 mm). Pocket has
// ~0.8–1.2 mm XY clearance and extra Z so the holder sits fully in the well.
// A 2x AA holder (Keystone 2463/2462, ~58 x 32 x 17) locates against −Y; print aa_2x_shim
// into the leftover +Y slack. Same well, no second pocket.
batt_pocket = [60, 50, 18];
batt_origin = [11, wall, wall]; // between the −Y cover posts
aa_2x_w = 32.8;
aa_shim = [batt_pocket[0] - 0.8, batt_pocket[1] - aa_2x_w, 16];

// MT3608 boost ~36 x 17 x 7 mm, set to 5.0 V, output through Schottky to VIN.
// Sits +X of the AA well, north of the front-left cover post.
boost = [36, 17, 7];
boost_origin = [batt_origin[0] + batt_pocket[0] + 2, batt_origin[1] + 12, wall];

// SS-12F15 on rear wall, between the AA well and ESP32 USB.
sw_y = batt_origin[1] + batt_pocket[1] + 2;
sw_z = 8;
sw_slot = [10, 5];

// Cover screws in corner posts that do not invade the AA well.
cover_x1 = 6;
cover_x2 = base_x - 6;
cover_y1 = 6;
cover_y2 = base_y - 6;

// P-clip M3 through the floor, +Y inner wall, −X of the jack.
// Clears the SJ1-3513N body and the +X+Y cover post.
pclip_x = base_x - 38;
pclip_y = base_y - wall - 6;

// USB-A → Micro-USB power-bank plug. Rear-wall window 18 x 12 mm
// (molded strain relief; the old 12 x 8 mm cut was too tight).
usb_cut_y = 18;
usb_cut_z = 12;
usb_cut_z0 = wall + 2;
// Second P-clip for the USB cable, floor just +Y of the DevKit USB.
usb_pclip_x = wall + 6;
usb_pclip_y = hinge_y + usb_cut_y / 2 + 1;

// McMaster 9271K22 LH 90° piano-wire torsion spring.
// 0.281" OD, 0.172" shaft, 0.030" wire, 3.25 coils, 1" legs, 0.67 in·lbf @ 90°.
spring_shaft_d = 4.4;  // 0.173" printed boss over the M3 hinge pin
spring_hole_d = 2.0;
spring_leg_r = 7.5;

// Method 4b later: TAL220 saddle M3 slots under the cam, outside the 40 mm pocket.
m4b_cx = hinge_x + cam_r;
m4b_dx = 24;

module cover_screw_xy() {
  for (px = [cover_x1, cover_x2])
    for (py = [cover_y1, cover_y2])
      translate([px, py, 0])
        children();
}

// --- chassis ---

module hinge_towers() {
  z0 = wall - 0.5;
  for (s = [-1, 1])
    translate([hinge_x - tower_d / 2, hinge_y + s * tower_off - tower_w / 2, z0])
      rounded_box([tower_d, tower_w, hinge_z + 7 - z0], 1.5);
  // spring shaft boss, inner face of left (−Y) tower, 9271K22 0.172" shaft
  translate([hinge_x, hinge_y - tower_off + tower_w / 2 - 1.5, hinge_z])
    rotate([-90, 0, 0])
      cylinder(h = 6.0, d = spring_shaft_d);
}

module base_chassis() {
  // Print: exterior floor on the bed (Z=0). Towers and wells point up.
  // Towers are added after the basin cut so they stay solid.
  difference() {
    union() {
      difference() {
        rounded_box([base_x, base_y, base_z], r_ext);

        // interior basin (open top)
        translate([wall, wall, wall])
          rounded_box([base_x - 2 * wall, base_y - 2 * wall, base_z], 1.2);

        // 3x AA well along X on −Y; 0.6 mm floor recess. 2x AA uses aa_2x_shim.
        translate([batt_origin[0], batt_origin[1], wall - 0.6])
          cube([batt_pocket[0], batt_pocket[1], batt_pocket[2] + 2]);

        // MT3608 well, +X of the AA holder (no TP4056 / no in-chassis charging)
        translate([boost_origin[0], boost_origin[1], wall - 0.4])
          cube([boost[0], boost[1], boost[2] + 4]);

        // SS-12F15 slide switch through rear wall (pack off in a bag)
        translate([-0.2, sw_y, sw_z - sw_slot[1] / 2])
          cube([wall + 6, sw_slot[0], sw_slot[1]]);

        // module pocket (open to interior, registered to cam)
        translate([module_origin[0], module_origin[1], module_origin[2]])
          cube([module_pocket[0], module_pocket[1], module_pocket[2] + 2]);

        // 8-pin 2.54 mm header well at rear of pocket: 3V3 GND SOFT HARD ADC SDA SCL ID
        translate([
          module_origin[0] - 3.2,
          module_origin[1] + module_pocket[1] / 2 - 10.8,
          wall + 2
        ])
          cube([4.0, 21.6, 10]);

        // ESP32 DevKit tray (USB toward −X / rear)
        translate([esp32_origin[0], esp32_origin[1], wall - 0.4])
          cube([esp32[0], esp32[1], esp32[2] + 6]);
        translate([-0.2, hinge_y - usb_cut_y / 2, usb_cut_z0])
          cube([wall + 6, usb_cut_y, usb_cut_z]);

        // USB-cable P-clip, −X inner floor, +Y of the USB window
        translate([usb_pclip_x, usb_pclip_y, -0.1])
          m3_clearance(h = wall + 2);

        // 3.5 mm jack well (SJ1-3513N), +Y wall, tip toward outside
        translate([base_x - 22, base_y - wall - 0.2, 8])
          rotate([-90, 0, 0])
            cylinder(h = wall + 6, d = 6.2);

        // P-clip / strain-relief M3 on +Y inner wall (not in the AA well)
        translate([pclip_x, pclip_y, -0.1])
          m3_clearance(h = wall + 2);

        // 1/4-20 brass insert, underside under the stick — not under the AA pack
        translate([base_x / 2, hinge_y, -0.1])
          cylinder(h = insert_1_4_20_h, d = insert_1_4_20_d);

        // 4x M3 tray slots, 20 mm, clear of the battery well
        for (px = [12, base_x - 12])
          for (py = [batt_origin[1] + batt_pocket[1] + 8, base_y - 10])
            translate([px, py, -0.1])
              rotate([0, 0, 90])
                m3_slot(length = 20, h = wall + 2);

        // Method 4b later: M3 slots under the cam, outside the 40 mm pocket
        for (dx = [-m4b_dx, m4b_dx])
          translate([m4b_cx + dx, hinge_y, -0.1])
            rotate([0, 0, 90])
              m3_slot(length = 12, h = wall + 2);

        translate([wall - 0.2, hinge_y + esp32[1] / 2 + 2, wall + 2])
          cube([wall + 1, 8, 6]);
      }

      hinge_towers();

      // cover-screw posts (inserts live here, not in empty basin)
      cover_screw_xy()
        translate([-4, -4, wall - 0.4])
          rounded_box([8, 8, base_z - wall + 0.4], 1.2);

      // module pocket floor (overlaps chassis floor so CGAL sees one volume)
      translate([module_origin[0], module_origin[1], wall - 0.4])
        cube([module_pocket[0], module_pocket[1], 2.0]);

      // rib between AA well and electronics so the holder cannot wander +Y
      translate([batt_origin[0], batt_origin[1] + batt_pocket[1] - 0.4, wall - 0.4])
        cube([batt_pocket[0], 2.0, 10.4]);
    }

    // module M2.5 inserts (34 x 26 mm) through the added pocket floor
    translate([
      module_origin[0] + (module_pocket[0] - module_holes[0]) / 2,
      module_origin[1] + (module_pocket[1] - module_holes[1]) / 2,
      wall - 0.1
    ]) {
      for (px = [0, module_holes[0]])
        for (py = [0, module_holes[1]])
          translate([px, py, 0]) {
            m25_insert(h = 5.2);
            cylinder(h = 2.2, d = 2.6);
          }
    }

    // cover M3 inserts through the corner posts
    cover_screw_xy()
      translate([0, 0, base_z - 6])
        m3_insert(h = 6.2);
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

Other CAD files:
cad/stl/mod3_ramp_cam.stl
cad/stl/wear_pad.stl
cad/stl/stick_collar.stl
cad/stl/magnet_plug.stl
cad/stl/bellows.stl
cad/stl/gap_gauge_3.stl
cad/stl/gap_gauge_5.stl
cad/stl/gap_gauge_6.stl
cad/stl/mod2_anvil.stl
cad/stl/mod4b_ball_anvil.stl
cad/stl/tpu_foot.stl

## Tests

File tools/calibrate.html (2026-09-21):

Skip to main content

# Stick-Switch calibrator

USB serial at 115200 baud. Open this page in Chrome or Edge (GitHub Pages is HTTPS, which Web Serial requires). Safari and Firefox cannot use Web Serial.

Plug the board in over USB (full kit: slide the power switch OFF while programming; USB-bank kit has no slide). Then connect here. Wired-only kits have no ESP32 — they do not use this calibrator. Calibration auto-saves to NVS; SAVE is only a confirmation dump. HID keys follow PROFILE (iPadOS default 1 / 2). Set PACK USB when there is no AA pack. The cable tester checks USB data with any browser-visible device; it does not test 3.5 mm PowerLink / TS cords.

Build instructions (https://github.com/grahamthetvi/Stick-Switch/blob/main/README.md) (GitHub README).

Disconnected

## Connect

Request the USB serial port, then open it at 115200. Disconnect when you unplug the board.

Connect Disconnect

## Cable tester

Plug a known-working USB device on the far end of the cable under test, then click a button and pick that device in the browser prompt. A keyboard, mouse, gamepad, ESP32, or USB-UART adapter is enough — Stick-Switch is not required.

This only infers a USB data path (D+/D−). Charge-only cables, broken data wires, and “nothing plugged in” all look the same: no device in the picker. Phones often never appear to Web Serial or WebHID. 3.5 mm TS / PowerLink cords are not USB — check those with a continuity meter (or a future jack loopback), not this tool.

Not tested yet

Look for a device through this cable

Serial is for ESP32 and USB-UART. HID is the “any device” path (keyboard, mouse, gamepad). WebUSB is optional and Chrome blocks many devices — do not rely on it alone.

Look for serial device Look for HID device Look for USB device

## Pack and profile

Device settings

Sensor mode

HID profile

Power

## Rest, soft, and hard wizard

Analog modules only (FSR / HALL / LOAD). Method 3 mechanical clicks do not need analog CAL.

1. Rest the stick, then TARE.
2. Hold the student’s soft press, start CAL SOFT, then stop.
3. Hold the student’s hard press, start CAL HARD, then stop.

Start: Rest / TARE

Manual calibration commands

TARE CAL SOFT CAL HARD CAL STOP DUMP SAVE PLOT ON PLOT OFF

## Live status

Values update from JSON the firmware sends (DUMP and live plot). Connection and errors are also announced above.

Mode

—

Level

—

Battery mV

—

Battery percent

—

Pack

—

Profile

—

Grip

—

Module ID

—

Serial log

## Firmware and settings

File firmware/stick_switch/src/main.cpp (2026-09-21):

#include <Arduino.h>
#include <Preferences.h>
#include <Wire.h>
#include <Adafruit_NAU7802.h>

#include <NimBLEDevice.h>
#include <BleKeyboard.h>
#include <esp_mac.h>

#include "config.h"
#include "hid_profile.h"
#include "pins.h"
#include "settings.h"
#include "stick_level.h"

namespace {

Preferences prefs;
char ble_name[20] = "Stick-Switch";
BleKeyboard ble(kBleName, kBleManufacturer, 100);
Adafruit_NAU7802 nau;
StickMachine machine;
StickSettings settings;
HidKeyset keys;

Debounce deb_soft(kDebounceMs);
Debounce deb_hard(kDebounceMs);
Debounce deb_aph(kDebounceMs);
Debounce deb_tare(kDebounceMs);
Debounce deb_cal(kDebounceMs);
Debounce deb_boot(kDebounceMs);
BoxcarFilter adc_filt(static_cast<float>(kBoxcar));
BoxcarFilter load_filt(static_cast<float>(kBoxcar));
BoxcarFilter grip_filt(4.0f);

bool nau_ok = false;
bool plot = false;
bool cal_collecting = false;
bool cal_is_hard = false;
float cal_acc[kCalSamples];
uint8_t cal_count = 0;
uint32_t last_adc_ms = 0;
uint32_t last_cal_sample_ms = 0;
uint32_t quiet_since_ms = 0;
bool analog_soft_held = false;
bool analog_hard_held = false;
char serial_buf[96];
uint8_t serial_len = 0;
int last_batt_mv = 0;
int last_batt_pct = -1;
int last_id_ohms = -1;
ModuleId last_module_id = ModuleId::Empty;
uint32_t last_batt_ms = 0;
bool last_ble_connected = false;
bool last_batt_low = false;
uint16_t last_grip_raw = 0;
bool last_grip = false;

bool sim_soft = false;
bool sim_hard = false;
uint32_t sim_until_ms = 0;

bool boot_was = false;
bool boot_held_fired = false;
uint8_t boot_taps = 0;
uint32_t boot_down_ms = 0;
uint32_t boot_wait_until = 0;

void handleLine(const String& line);

struct Earcon {
  uint16_t freq;
  uint16_t ms;
};

Earcon earcon_q[6];
uint8_t earcon_n = 0;
uint8_t earcon_i = 0;
uint32_t earcon_until = 0;
bool earcon_on = false;

const char* modeName(StickMode m) {
  switch (m) {
    case StickMode::Micro:
      return "MICRO";
    case StickMode::Fsr:
      return "FSR";
    case StickMode::Hall:
      return "HALL";
    case StickMode::Load:
      return "LOAD";
    case StickMode::Binary:
      return "BINARY";
    default: {
      const StickMode unused = m;
      (void)unused;
      return "MICRO";
    }
  }
}

StickMode parseMode(const String& s) {
  if (s == "MICRO") {
    return StickMode::Micro;
  }
  if (s == "FSR") {
    return StickMode::Fsr;
  }
  if (s == "HALL") {
    return StickMode::Hall;
  }
  if (s == "LOAD") {
    return StickMode::Load;
  }
  if (s == "BINARY") {
    return StickMode::Binary;
  }
  return settings.mode;
}

StickMode modeFromModuleId(ModuleId id) {
  switch (id) {
    case ModuleId::Micro:
      return StickMode::Micro;
    case ModuleId::Fsr:
      return StickMode::Fsr;
    case ModuleId::Hall:
      return StickMode::Hall;
    case ModuleId::Load:
      return StickMode::Load;
    case ModuleId::Empty:
      return settings.mode;
    default: {
      const ModuleId unused = id;
      (void)unused;
      return StickMode::Micro;
    }
  }
}

void refreshKeys() {
  keys = keysetFor(settings.profile, settings);
}

void saveSettings() {
  prefs.begin("stick", false);
  prefs.putUChar("mode", static_cast<uint8_t>(settings.mode));
  prefs.putUChar("prof", static_cast<uint8_t>(settings.profile));
  prefs.putUChar("pack", static_cast<uint8_t>(settings.pack));
  prefs.putBool("inv_sw", settings.invert_switches);
  prefs.putBool("inv_an", settings.invert_analog);
  prefs.putBool("inv_ld", settings.invert_load);
  prefs.putChar("ksoft", settings.key_soft);
  prefs.putChar("khard", settings.key_hard);
  prefs.putChar("kbin", settings.key_binary);
  prefs.putInt("tare", settings.tare_adc);
  prefs.putInt("fsr_s", settings.fsr_soft_on);
  prefs.putInt("fsr_h", settings.fsr_hard_on);
  prefs.putFloat("h_s", settings.hall_soft_mm);
  prefs.putFloat("h_h", settings.hall_hard_mm);
  prefs.putBytes("h_adc", settings.hall_adc, sizeof(settings.hall_adc));
  prefs.putBytes("h_mm", settings.hall_mm, sizeof(settings.hall_mm));
  prefs.putInt("ld_tare", settings.load_tare);
  prefs.putFloat("ld_sc", settings.load_scale);
  prefs.putFloat("ld_s", settings.load_soft_gf);
  prefs.putFloat("ld_h", settings.load_hard_gf);
  prefs.putUShort("gth", settings.grip_thresh);
  prefs.end();
}

void persist(bool announce) {
  saveSettings();
  if (announce) {
    Serial.println(F("{\"saved\":true}"));
  }
}

void loadSettings() {
  prefs.begin("stick", true);
  settings.mode = static_cast<StickMode>(prefs.getUChar("mode", 0));
  settings.profile = static_cast<HidProfile>(prefs.getUChar("prof", 0));
  settings.pack = static_cast<PackType>(prefs.getUChar("pack", 0));
  settings.invert_switches = prefs.getBool("inv_sw", false);
  settings.invert_analog = prefs.getBool("inv_an", false);
  settings.invert_load = prefs.getBool("inv_ld", false);
  settings.key_soft = prefs.getChar("ksoft", kKeySoft);
  settings.key_hard = prefs.getChar("khard", kKeyHard);
  settings.key_binary = prefs.getChar("kbin", kKeyBinary);
  settings.tare_adc = prefs.getInt("tare", 0);
  settings.fsr_soft_on = prefs.getInt("fsr_s", kFsrSoftCounts);
  settings.fsr_hard_on = prefs.getInt("fsr_h", kFsrHardCounts);
  settings.hall_soft_mm = prefs.getFloat("h_s", kHallSoftMm);
  settings.hall_hard_mm = prefs.getFloat("h_h", kHallHardMm);
  prefs.getBytes("h_adc", settings.hall_adc, sizeof(settings.hall_adc));
  prefs.getBytes("h_mm", settings.hall_mm, sizeof(settings.hall_mm));
  settings.load_tare = prefs.getInt("ld_tare", 0);
  settings.load_scale = prefs.getFloat("ld_sc", 1.0f);
  settings.load_soft_gf = prefs.getFloat("ld_s", kLoadSoftGf);
  settings.load_hard_gf = prefs.getFloat("ld_h", kLoadHardGf);
  settings.grip_thresh = prefs.getUShort("gth", kGripThreshDefault);
  prefs.end();
  if (settings.hall_adc[kHallLutPoints - 1] <= settings.hall_adc[0]) {
    settings.hall_adc[0] = 1800;
    settings.hall_adc[1] = 2000;
    settings.hall_adc[2] = 2300;
    settings.hall_adc[3] = 2700;
    settings.hall_adc[4] = 3100;
    settings.hall_mm[0] = 0;
    settings.hall_mm[1] = 3;
    settings.hall_mm[2] = 6;
    settings.hall_mm[3] = 9;
    settings.hall_mm[4] = 12;
  }
  if (settings.grip_thresh == 0) {
    settings.grip_thresh = kGripThreshDefault;
  }
  refreshKeys();
}

void enqueueTone(uint16_t freq, uint16_t ms) {
  if (earcon_n >= 6) {
    return;
  }
  earcon_q[earcon_n].freq = freq;
  earcon_q[earcon_n].ms = ms;
  earcon_n++;
}

void earconStartup() {
  enqueueTone(880, 80);
  enqueueTone(0, 40);
  enqueueTone(1175, 80);
}

void earconPaired() {
  enqueueTone(1200, 60);
  enqueueTone(0, 30);
  enqueueTone(1600, 80);
}

void earconClick() {
  enqueueTone(2000, 18);
}

void earconLowBatt() {
  enqueueTone(400, 120);
  enqueueTone(0, 80);
  enqueueTone(400, 120);
}

void pollBuzzer(uint32_t now) {
  if (!earcon_on) {
    if (earcon_i >= earcon_n) {
      earcon_n = 0;
      earcon_i = 0;
      return;
    }
    const Earcon& t = earcon_q[earcon_i];
    if (t.freq > 0) {
      ledcWriteTone(kBuzzerChannel, t.freq);
    } else {
      ledcWriteTone(kBuzzerChannel, 0);
    }
    earcon_until = now + t.ms;
    earcon_on = true;
    return;
  }
  if (now >= earcon_until) {
    ledcWriteTone(kBuzzerChannel, 0);
    earcon_on = false;
    earcon_i++;
  }
}

void hidPress(const HidKey& k) {
  switch (k.kind) {
    case HidKeyKind::Keyboard:
      ble.press(k.kbd);
      break;
    case HidKeyKind::Media: {
      MediaKeyReport r;
      r[0] = k.media0;
      r[1] = k.media1;
      ble.press(r);
      break;
    }
    default: {
      const HidKeyKind unused = k.kind;
      (void)unused;
      break;
    }
  }
}

void hidRelease(const HidKey& k) {
  switch (k.kind) {
    case HidKeyKind::Keyboard:
      ble.release(k.kbd);
      break;
    case HidKeyKind::Media: {
      MediaKeyReport r;
      r[0] = k.media0;
      r[1] = k.media1;
      ble.release(r);
      break;
    }
    default: {
      const HidKeyKind unused = k.kind;
      (void)unused;
      break;
    }
  }
}

void applyHid(const HidAction& a) {
  if (!ble.isConnected() || a.empty()) {
    return;
  }
  if (a.release_soft) {
    hidRelease(keys.soft);
  }
  if (a.release_hard) {
    hidRelease(keys.hard);
  }
  if (a.release_binary) {
    hidRelease(keys.binary);
  }
  if (a.press_soft) {
    hidPress(keys.soft);
  }
  if (a.press_hard) {
    hidPress(keys.hard);
  }
  if (a.press_binary) {
    hidPress(keys.binary);
  }
  if (a.press_soft || a.press_hard || a.press_binary) {
    earconClick();
  }
}

void setLeds(StickLevel level, bool binary) {
  const bool soft = level == StickLevel::Soft || binary;
  const bool hard = level == StickLevel::Hard;
  digitalWrite(PIN_LED_SOFT, soft ? HIGH : LOW);
  digitalWrite(PIN_LED_HARD, hard ? HIGH : LOW);
}

void setJack(bool closed) {
  digitalWrite(PIN_JACK_OUT, closed ? HIGH : LOW);
}

int analogReadFilt() {
  analogSetPinAttenuation(PIN_ADC_SENSOR, ADC_11db);
  const int raw = analogRead(PIN_ADC_SENSOR);
  const float v = adc_filt.push(static_cast<float>(raw));
  return static_cast<int>(v);
}

int readBattMv() {
  analogSetPinAttenuation(PIN_ADC_BATT, ADC_11db);
  int acc = 0;
  for (int i = 0; i < 8; ++i) {
    acc += analogRead(PIN_ADC_BATT);
  }
  return battMvFromAdc(acc / 8, kAdcVrefMv, kAdcFullScale);
}

void readModuleId() {
  analogSetPinAttenuation(PIN_MODULE_ID, ADC_11db);
  int acc = 0;
  for (int i = 0; i < 8; ++i) {
    acc += analogRead(PIN_MODULE_ID);
  }
  last_module_id = decodeModuleId(acc / 8, &last_id_ohms, kModuleIdPullupOhms, kAdcFullScale);
}

void pollGrip() {
  last_grip_raw = static_cast<uint16_t>(grip_filt.push(static_cast<float>(touchRead(PIN_TOUCH_GRIP))));
  last_grip = gripHolding(last_grip_raw, settings.grip_thresh);
  digitalWrite(PIN_LED_GRIP, last_grip ? HIGH : LOW);
}

void maybeLowBattLeds(uint32_t now, bool active) {
  if (active || last_batt_mv == 0 || !battIsLow(last_batt_mv, settings.pack)) {
    return;
  }
  const bool on = ((now / kBattBlinkMs) % 2) == 0;
  digitalWrite(PIN_LED_SOFT, on ? HIGH : LOW);
  digitalWrite(PIN_LED_HARD, on ? HIGH : LOW);
}

void publishBattery(bool force) {
  const int pct = battPctFromMv(last_batt_mv, settings.pack);
  if (!ble.isConnected()) {
    last_batt_pct = -1;
    return;
  }
  if (force || pct != last_batt_pct) {
    last_batt_pct = pct;
    ble.setBatteryLevel(static_cast<uint8_t>(pct));
  }
}

float hallMm(int adc) {
  float v = static_cast<float>(adc);
  if (settings.invert_analog) {
    v = 4095.0f - v;
  }
  return lutInterp(settings.hall_adc, settings.hall_mm, kHallLutPoints, v);
}

float loadGrams() {
  if (!nau_ok) {
    return 0.0f;
  }
  const int32_t raw = nau.read();
  int32_t centered = raw - settings.load_tare;
  if (settings.invert_load) {
    centered = -centered;
  }
  const float g = load_filt.push(static_cast<float>(centered) * settings.load_scale);
  return g;
}

void printKeyJson(const HidKey& k) {
  if (k.kind == HidKeyKind::Media) {
    Serial.print("\"M");
    Serial.print(k.media0);
    if (k.media1) {
      Serial.print(",");
      Serial.print(k.media1);
    }
    Serial.print("\"");
    return;
  }
  if (k.kbd == ' ') {
    Serial.print("\"SPACE\"");
    return;
  }
  if (k.kbd >= 32 && k.kbd < 127) {
    Serial.print("\"");
    Serial.print(static_cast<char>(k.kbd));
    Serial.print("\"");
    return;
  }
  Serial.print(k.kbd);
}

void dumpJson() {
  Serial.print("{\"mode\":\"");
  Serial.print(modeName(settings.mode));
  Serial.print("\",\"profile\":\"");
  Serial.print(profileName(settings.profile));
  Serial.print("\",\"ble_name\":\"");
  Serial.print(ble_name);
  Serial.print("\",\"level\":");
  Serial.print(static_cast<int>(machine.level()));
  Serial.print(",\"batt_mv\":");
  Serial.print(last_batt_mv);
  Serial.print(",\"batt_pct\":");
  Serial.print(battPctFromMv(last_batt_mv, settings.pack));
  Serial.print(",\"pack\":");
  Serial.print(packCells(settings.pack));
  Serial.print(",\"grip\":");
  Serial.print(last_grip ? "true" : "false");
  Serial.print(",\"grip_raw\":");
  Serial.print(last_grip_raw);
  Serial.print(",\"grip_thresh\":");
  Serial.print(settings.grip_thresh);
  Serial.print(",\"module_id\":\"");
  Serial.print(moduleIdName(last_module_id));
  Serial.print("\",\"module_ohms\":");
  Serial.print(last_id_ohms);
  Serial.print(",\"tare_adc\":");
  Serial.print(settings.tare_adc);
  Serial.print(",\"fsr_soft\":");
  Serial.print(settings.fsr_soft_on);
  Serial.print(",\"fsr_hard\":");
  Serial.print(settings.fsr_hard_on);
  Serial.print(",\"hall_soft_mm\":");
  Serial.print(settings.hall_soft_mm);
  Serial.print(",\"hall_hard_mm\":");
  Serial.print(settings.hall_hard_mm);
  Serial.print(",\"load_tare\":");
  Serial.print(settings.load_tare);
  Serial.print(",\"load_scale\":");
  Serial.print(settings.load_scale, 6);
  Serial.print(",\"load_soft_gf\":");
  Serial.print(settings.load_soft_gf);
  Serial.print(",\"load_hard_gf\":");
  Serial.print(settings.load_hard_gf);
  Serial.print(",\"keys\":[");
  printKeyJson(keys.soft);
  Serial.print(",");
  printKeyJson(keys.hard);
  Serial.print(",");
  printKeyJson(keys.binary);
  Serial.print("],\"hall_lut\":[");
  for (uint8_t i = 0; i < kHallLutPoints; ++i) {
    if (i) {
      Serial.print(",");
    }
    Serial.print("[");
    Serial.print(settings.hall_adc[i]);
    Serial.print(",");
    Serial.print(settings.hall_mm[i]);
    Serial.print("]");
  }
  Serial.println("]}");
}

void help() {
  Serial.println(F("MODE MICRO|FSR|HALL|LOAD|BINARY"));
  Serial.println(F("PROFILE IPADOS|ANDROID|FUNCTION|MEDIA|CUSTOM"));
  Serial.println(F("PACK 2|3|USB"));
  Serial.println(F("TARE"));
  Serial.println(F("CAL START SOFT|HARD"));
  Serial.println(F("CAL STOP"));
  Serial.println(F("LUT adc0,mm0,adc1,mm1,adc2,mm2,adc3,mm3,adc4,mm4"));
  Serial.println(F("SCALE <gf_per_count>"));
  Serial.println(F("INVERT SW|AN|LD 0|1"));
  Serial.println(F("KEYS <soft><hard>   example: KEYS 12"));
  Serial.println(F("BINARY_KEY SPACE|1|2"));
  Serial.println(F("GRIP THRESH <n>"));
  Serial.println(F("GRIP CAL"));
  Serial.println(F("SAVE  DUMP  PLOT 0|1  HELP"));
}

void finishCal() {
  if (cal_count == 0) {
    Serial.println(F("{\"cal\":\"empty\"}"));
    cal_collecting = false;
    return;
  }
  float sum = 0;
  for (uint8_t i = 0; i < cal_count; ++i) {
    sum += cal_acc[i];
  }
  const float mean = sum / cal_count;
  if (settings.mode == StickMode::Fsr) {
    if (cal_is_hard) {
      const float span = mean - static_cast<float>(settings.tare_adc);
      settings.fsr_hard_on = static_cast<int32_t>(0.70f * span);
      settings.fsr_soft_on = static_cast<int32_t>(0.35f * span);
    } else {
      settings.fsr_soft_on = static_cast<int32_t>(mean - static_cast<float>(settings.tare_adc));
    }
  } else if (settings.mode == StickMode::Hall) {
    if (cal_is_hard) {
      settings.hall_hard_mm = mean;
    } else {
      settings.hall_soft_mm = mean;
    }
  } else if (settings.mode == StickMode::Load) {
    if (cal_is_hard) {
      settings.load_hard_gf = mean;
      settings.load_soft_gf = 0.40f * mean;
    } else {
      settings.load_soft_gf = mean;
    }
  }
  cal_collecting = false;
  cal_count = 0;
  persist(false);
  Serial.print(F("{\"cal\":\"ok\",\"mean\":"));
  Serial.print(mean);
  Serial.println("}");
}

void doTare() {
  if (settings.mode == StickMode::Load && nau_ok) {
    int64_t acc = 0;
    for (int i = 0; i < 16; ++i) {
      while (!nau.available()) {
        delay(2);
      }
      acc += nau.read();
    }
    settings.load_tare = static_cast<int32_t>(acc / 16);
    load_filt.set(0);
  } else {
    int64_t acc = 0;
    const uint32_t start = millis();
    int n = 0;
    while (millis() - start < kTareWindowMs) {
      acc += analogRead(PIN_ADC_SENSOR);
      n++;
      delay(5);
    }
    settings.tare_adc = static_cast<int32_t>(acc / max(n, 1));
    adc_filt.set(static_cast<float>(settings.tare_adc));
  }
  Serial.println(F("{\"tare\":true}"));
  persist(false);
  dumpJson();
}

void doCalToggle() {
  if (!cal_collecting) {
    handleLine(analog_hard_held ? String("CAL START HARD") : String("CAL START SOFT"));
  } else {
    handleLine("CAL STOP");
  }
}

void simulateLevel(bool hard) {
  sim_soft = !hard;
  sim_hard = hard;
  sim_until_ms = millis() + kSimPulseMs;
}

void bootHoldAction() {
  if (cal_collecting || analog_soft_held || analog_hard_held) {
    doCalToggle();
  } else {
    doTare();
  }
}

void pollBoot(uint32_t now) {
  const bool down = deb_boot.update(digitalRead(PIN_BTN_BOOT) == LOW, now);
  if (down && !boot_was) {
    boot_down_ms = now;
    boot_held_fired = false;
  }
  if (down && !boot_held_fired && (now - boot_down_ms) >= kBootHoldMs) {
    boot_held_fired = true;
    boot_taps = 0;
    bootHoldAction();
  }
  if (!down && boot_was && !boot_held_fired) {
    boot_taps++;
    boot_wait_until = now + kBootTapGapMs;
  }
  if (!down && boot_taps > 0 && now >= boot_wait_until) {
    if (boot_taps == 1) {
      simulateLevel(false);
    } else {
      simulateLevel(true);
    }
    boot_taps = 0;
  }
  boot_was = down;
}
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
void loop() {
  const uint32_t now = millis();
  pollSerial();
  pollBuzzer(now);
  pollGrip();
  pollBoot(now);

  if (now - last_batt_ms >= kBattPollMs) {
    last_batt_ms = now;
    last_batt_mv = readBattMv();
    publishBattery(false);
    const bool low = battIsLow(last_batt_mv, settings.pack);
    if (low && !last_batt_low) {
      earconLowBatt();
    }
    last_batt_low = low;
  }

  const bool connected = ble.isConnected();
  if (connected && !last_ble_connected) {
    publishBattery(true);
    earconPaired();
  }
  last_ble_connected = connected;

  const bool tare_btn = deb_tare.update(digitalRead(PIN_BTN_TARE) == LOW, now);
  static bool tare_was = false;
  if (tare_btn && !tare_was) {
    handleLine("TARE");
  }
  tare_was = tare_btn;

  const bool cal_btn = deb_cal.update(digitalRead(PIN_BTN_CAL) == LOW, now);
  static bool cal_was = false;
  if (cal_btn && !cal_was) {
    doCalToggle();
  }
  cal_was = cal_btn;

  if (sim_until_ms != 0 && now >= sim_until_ms) {
    sim_soft = false;
    sim_hard = false;
    sim_until_ms = 0;
  }

  bool soft = false;
  bool hard = false;
  bool aph = false;
  readSoftHard(now, &soft, &hard, &aph);
  soft = soft || sim_soft;
  hard = hard || sim_hard;

  HidAction action;
  bool jack = false;
  if (settings.mode == StickMode::Binary) {
    action = machine.updateBinary(soft || hard || aph);
    jack = soft || hard || aph;
    setLeds(StickLevel::Idle, jack);
  } else {
    action = machine.updateDual(soft, hard);
    const HidAction aph_action = machine.updateBinary(aph);
    action.release_binary = aph_action.release_binary;
    action.press_binary = aph_action.press_binary;
    jack = machine.level() != StickLevel::Idle || aph;
    setLeds(machine.level(), aph);
  }
  applyHid(action);
  setJack(jack);
  maybeLowBattLeds(now, jack);

  static uint32_t last_plot = 0;
  if (plot && now - last_plot > 50) {
    last_plot = now;
    Serial.print(F("lvl="));
    Serial.print(static_cast<int>(machine.level()));
    Serial.print(F(" s="));
    Serial.print(soft);
    Serial.print(F(" h="));
    Serial.print(hard);
    Serial.print(F(" g="));
    Serial.println(last_grip);
  }
}

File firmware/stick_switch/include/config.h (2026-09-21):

#pragma once

#include <cstdint>

enum class StickMode : uint8_t {
  Micro = 0,
  Fsr = 1,
  Hall = 2,
  Load = 3,
  Binary = 4,
};

enum class PackType : uint8_t {
  Unset = 0,
  Usb = 1,
  Cell2 = 2,
  Cell3 = 3,
};

enum class HidProfile : uint8_t {
  IpadOS = 0,
  Android = 1,
  Function = 2,
  Media = 3,
  Custom = 4,
};

constexpr const char* kBleName = "Stick-Switch";
constexpr const char* kBleManufacturer = "Graham Labs";
constexpr char kKeySoft = '1';
constexpr char kKeyHard = '2';
constexpr char kKeyBinary = ' ';

constexpr uint32_t kDebounceMs = 15;
constexpr uint32_t kAdcHz = 200;
constexpr uint8_t kBoxcar = 8;
constexpr float kHysteresisFrac = 0.08f;

constexpr int kFsrSoftCounts = 250;
constexpr int kFsrHardCounts = 1200;
constexpr float kHallSoftMm = 5.0f;
constexpr float kHallHardMm = 11.0f;
constexpr float kHallHystMm = 0.8f;
constexpr float kLoadSoftGf = 120.0f;
constexpr float kLoadHardGf = 300.0f;
constexpr float kLoadHystGf = 25.0f;
constexpr float kLoadQuietGf = 15.0f;
constexpr uint32_t kLoadSlowTareMs = 3000;

constexpr uint8_t kHallLutPoints = 5;
constexpr uint16_t kCalSamples = 5;
constexpr uint32_t kTareWindowMs = 1000;

constexpr int kAdcVrefMv = 3300;
constexpr int kAdcFullScale = 4095;
constexpr int kModuleIdPullupOhms = 47000;
constexpr uint32_t kBattPollMs = 500;
constexpr uint32_t kBattBlinkMs = 700;
constexpr uint8_t kBattLowPct = 15;

// Alkaline-ish AA series. 2x empty ~2.0 V full ~3.2 V; 3x empty ~3.0 V full ~4.8 V.
constexpr int kPack2EmptyMv = 2000;
constexpr int kPack2FullMv = 3200;
constexpr int kPack3EmptyMv = 3000;
constexpr int kPack3FullMv = 4800;
constexpr int kPackAuto3Mv = 3300;

constexpr uint16_t kGripThreshDefault = 40;
constexpr uint32_t kBootHoldMs = 800;
constexpr uint32_t kBootTapGapMs = 350;
constexpr uint32_t kSimPulseMs = 100;
constexpr uint8_t kBuzzerChannel = 4;

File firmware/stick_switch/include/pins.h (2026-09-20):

#pragma once

#include <cstdint>

// ESP32 DevKit V1 / WROOM. ADC1 only — BLE uses the radio; ADC2 is forbidden.
// GPIO0 is the ESP32 BOOT strap; pinMode runs in setup() after the bootloader.

constexpr int PIN_SW_SOFT = 18;
constexpr int PIN_SW_HARD = 19;
constexpr int PIN_APH_BACKUP = 33;
constexpr int PIN_ADC_SENSOR = 32;  // ADC1_CH4
constexpr int PIN_I2C_SDA = 21;
constexpr int PIN_I2C_SCL = 22;
constexpr int PIN_BTN_TARE = 4;
constexpr int PIN_BTN_CAL = 23;
constexpr int PIN_BTN_BOOT = 0;     // 1 tap soft, 2 taps hard, hold tare/cal
constexpr int PIN_LED_SOFT = 25;
constexpr int PIN_LED_HARD = 26;
constexpr int PIN_LED_GRIP = 16;    // indicator only — never HID, never jack
constexpr int PIN_JACK_OUT = 27;    // 2N7000 gate for analog modules
constexpr int PIN_ADC_BATT = 34;    // ADC1_CH6, 100k/100k from pack + (before boost)
constexpr int PIN_MODULE_ID = 35;   // ADC1_CH7, header pin 8; 47k pull-up on chassis
constexpr int PIN_TOUCH_GRIP = 14;  // T6, isolated 6061 tube through PETG collar
constexpr int PIN_BUZZER = 13;      // optional piezo; silent if unpopulated

// 8-pin module header, rear of bay, pin 1 = 3V3:
// 1 3V3 | 2 GND | 3 SOFT | 4 HARD | 5 ADC | 6 SDA | 7 SCL | 8 ID (GPIO35)

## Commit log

2026-09-17 Add chassis CAD, firmware, and print-ready STLs.
    Publish the two-level stick-switch design so the GitHub repo has CAD, ESP32 firmware, BOM, and OpenSCAD-exported parts instead of an empty initial commit.
    [base_chassis.stl, bellows.stl, bom.csv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]
2026-09-17 Enhance README and CAD files for stick-switch project.
    Updated the README to include detailed printing instructions for the first classroom experiment, including a table of parts and materials. Improved CAD files with new design features, including modul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
    [base_chassis.stl, bellows.stl, bom.csv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]
2026-09-20 Update README, CAD files, and firmware for stick-switch project.
    Enhanced the README with a comprehensive first-kit print list and build instructions. Updated CAD files to include the new `aa_2x_shim` part for 2x AA holders and adjusted design elements for improve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
    [aa_2x_shim.stl, base_chassis.stl, bom.csv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]
2026-09-20 Refactor GitHub Pages setup and update README for Stick-Switch project.
    Removed Jekyll configuration and layout files, transitioning to a simpler static site structure. Updated the README to clarify the purpose of the Web Serial calibrator and its usage instructions. Enh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
    This change streamlines the deployment process and ensures the documentation is more user-friendly.
2026-09-21 Enhance README and calibrate HTML for Stick-Switch project.
    Updated the README to include a USB cable tester feature, clarifying its functionality and limitations. Enhanced the calibrate HTML with a new section for cable testing, allowing users to check USB d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
    This update aims to improve user experience and provide clearer instructions for testing USB cables.
2026-09-21 update to bom
    [bom.csv]
2026-09-21 Update README, CAD files, and BOM for stick-switch project.
    Enhanced the README to include the new `p_clip` part, detailing its printing instructions and usage. Updated CAD files to reflect changes in slot dimensions and added the `p_clip` module for improved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
    This update aims to improve documentation and component integration for the stick-switch project.
    [base_chassis.stl, bom.csv, lib.scad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]
2026-09-21 Enhance README, CAD files, and firmware for USB power bank integration in stick-switch project.
    Updated the README to include instructions for using a USB power bank, detailing the necessary components and modifications. Enhanced CAD files to accommodate a second `p_clip` for USB cable manageme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
    This update aims to improve usability and documentation for users integrating USB power solutions.
    [base_chassis.stl, bom.csv, cover_slot.stl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]
2026-09-21 Update README, CAD files, and BOM for stick-switch project to clarify kit configurations and printing instructions.
    Enhanced the README to specify the differences between the wired, USB bank, and full kits, including detailed printing instructions and component requirements. Updated CAD files to reflect shared pri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
    This update aims to improve documentation and usability for users assembling different configurations of the stick-switch project.
    [bom.csv, stick_switch.scad]
